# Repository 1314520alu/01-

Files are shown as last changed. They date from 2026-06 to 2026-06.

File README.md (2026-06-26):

# 01飞控 — X9 Core 多旋翼底板

为零一飞行 [X9 Core](https://docs.01aero.cn/docs/JfRLkT8E) 设计多旋翼载板（EasyEDA）。

## 文档

| 文件 | 说明 |
|---|---|
| [docs/X9-Core-多旋翼底板-接口设计说明.md](docs/X9-Core-多旋翼底板-接口设计说明.md) | 接口需求、电源架构、串口映射、PWM/CAN 分配 |
| [docs/DF17/](docs/DF17/) | DF17 引脚：Core（[80DS](docs/DF17/DF17-80DS-pinout.md)/[80DP](docs/DF17/DF17-80DP-pinout.md)）+ 载板（[carrier-80DS](docs/DF17/carrier-80DS-pinout.md)/[carrier-80DP](docs/DF17/carrier-80DP-pinout.md)） |
| [db/pinout.db](db/pinout.db) | SQLite 引脚库（`python tools/import_df17_pinout.py` 同步） |
| [docs/DF17/cad/](docs/DF17/cad/) | X9 Core 底面 DXF 机械图 |

## 下一步

1. 向零一飞行索取 **DF17 封装尺寸 DXF**（pinout 已录入 [docs/DF17/](docs/DF17/)）
2. 在 EasyEDA 按设计说明第 9 节分区绘制原理图
3. 载板原理图标网以 [carrier-80DS/80DP](docs/DF17/) 为准（载板 DS←Core DP，载板 DP←Core DS）

## 固件

- 机型：**ArduCopter**
- 固件：[零一 X9 ArduPilot 资源](https://pan.01aero.cn/s/mYhv零一飞行资源库/X9系列飞控/ArduPilot固件)

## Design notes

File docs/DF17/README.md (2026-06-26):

# DF17 连接器资料

X9 Core 底部有两颗 **80pin** 板对板 DF17 连接器，载板设计需同时对接。

## 参考图

| 图 | 说明 |
|----|---|
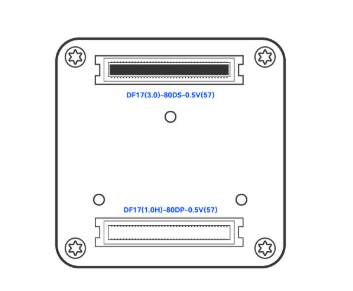
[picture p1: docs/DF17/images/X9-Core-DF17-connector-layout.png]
座子布局
|  | 飞控底部两颗 DF17 位置（上 **80DS**、下 **80DP**） |
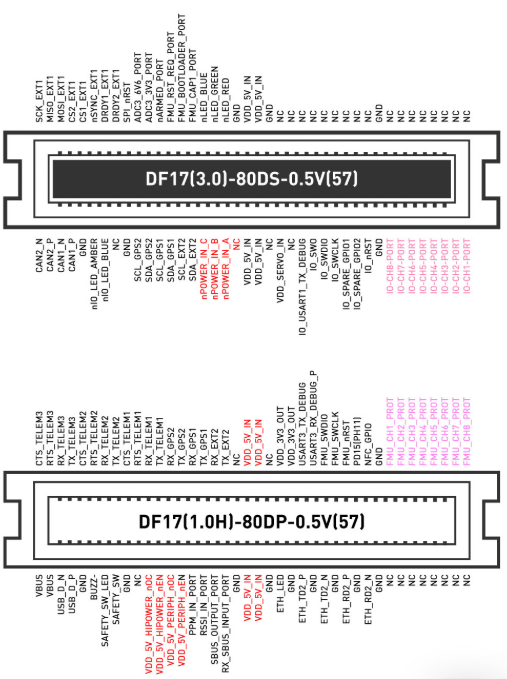
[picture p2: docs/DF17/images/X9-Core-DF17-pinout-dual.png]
双座子引脚图
|  | 80DS + 80DP 完整引脚图（官方） |

源文件：

- [images/X9-Core-DF17-connector-layout.png](images/X9-Core-DF17-connector-layout.png)
- [images/X9-Core-DF17-pinout-dual.png](images/X9-Core-DF17-pinout-dual.png)

## CAD（底面机械）

| 文件 | 说明 |
|---|---|
| [cad/X9-Core-bottom.dxf](cad/X9-Core-bottom.dxf) | Core 底面机械 DXF |
| [cad/carrier-pcb.dxf](cad/carrier-pcb.dxf) | **载板 PCB DXF**（Top View，导入 EasyEDA） |
| [cad/X9-Core-bottom-reference.png](cad/X9-Core-bottom-reference.png) | 官方底面机械图 |
| [cad/README.md](cad/README.md) | 图层、尺寸、生成说明 |

```bash
pip install ezdxf
python tools/generate_x9_bottom_cad.py
python tools/generate_carrier_pcb_dxf.py
```

## 原理图（Core 载板 · 仅双 DF17）

| 文件 | 说明 |
|---|---|
| [schematic/Core底板-原理图.md](schematic/Core底板-原理图.md) | 单页原理图规格：J1(80DP) + J2(80DS) |
| [schematic/core-carrier-schematic-spec.json](schematic/core-carrier-schematic-spec.json) | 机器可读引脚/布局规格 |

生成：`python tools/setup_core_carrier_schematic.py`

## JLCEDA MCP

Cursor ↔ 嘉立创 EDA 桥接：`ws://127.0.0.1:8760/bridge/ws`  
配置与故障修复见 [JLCEDA-MCP-配置与修复.md](JLCEDA-MCP-配置与修复.md)

| 座子型号 | 文档 | 视角 | 主要功能 |
|---|---|---|---|
| DF17(3.0)-80DS-0.5V(57) | [DF17-80DS-pinout.md](DF17-80DS-pinout.md) | **Core** | SPI、CAN、I2C、IO 侧 PWM/SWD |
| DF17(1.0H)-80DP-0.5V(57) | [DF17-80DP-pinout.md](DF17-80DP-pinout.md) | **Core** | UART、FMU PWM、以太网、USB、RC、电源控制 |
| DF17(3.0)-80DS-0.5V(57) | [carrier-80DS-pinout.md](carrier-80DS-pinout.md) | **载板 −Y** | 对接 Core 80DP，网络同 Core DP 表 |
| DF17(1.0H)-80DP-0.5V(57) | [carrier-80DP-pinout.md](carrier-80DP-pinout.md) | **载板 +Y** | 对接 Core 80DS，网络同 Core DS 表 |

## 原理图放置（LCSC 标准符号）

**原理图页面**与 Core 官方引脚图同序（上 80DS、下 80DP），便于对照；**PCB 贴装**仍为 +Y=80DP、−Y=80DS。

| 原理图 | 座子 | PCB | rotation | mirror | Pin1 位置 |
|---|---|-----|---|---|---|
| 上 J1 | 80DS | −Y | **90** | **true** | 右上 |
| 下 J2 | 80DP | +Y | **270** | **true** | 左下 |

各座子标网取自 **载板引脚表**（[carrier-80DS](carrier-80DS-pinout.md) / [carrier-80DP](carrier-80DP-pinout.md)：载板 DS←Core DP，载板 DP←Core DS）。

勿用 rotation=270 **无**镜像，或两座子相同 rotation——会导致与 Core 文档不对称。

## 数据库

结构化数据存放在 SQLite：`db/pinout.db`

| 文件 | 说明 |
|---|---|
| [db/schema.sql](../db/schema.sql) | 表结构（products / connectors / pins） |
| [tools/import_df17_pinout.py](../tools/import_df17_pinout.py) | 从 Markdown 导入/更新数据库 |

```bash
python tools/generate_carrier_pinout_md.py   # 从 Core md 生载板 md
python tools/import_df17_pinout.py
python tools/setup_core_carrier_schematic.py
```

常用查询示例：

```sql
-- 载板 80DP 全部引脚
SELECT pin_number, signal_name, category
FROM pins p JOIN connectors c ON p.connector_id = c.id
WHERE c.part_number = 'DF17(1.0H)-80DP-0.5V(57)' AND c.role = 'carrier'
ORDER BY pin_number;

-- Core 80DS 全部引脚
SELECT pin_number, signal_name, category
FROM pins p JOIN connectors c ON p.connector_id = c.id
WHERE c.part_number = 'DF17(3.0)-80DS-0.5V(57)' AND c.role = 'core'
ORDER BY pin_number;

-- 按信号名搜索（含载板）
SELECT c.role, c.part_number, p.pin_number, p.signal_name
FROM pins p JOIN connectors c ON p.connector_id = c.id
WHERE p.signal_name LIKE '%CAN%'
ORDER BY c.role, c.part_number, p.pin_number;
```

## 编号约定

**Core 底视**（两颗座子相同）：

- 上排奇数：**1, 3, 5, …, 79**（左 → 右）
- 下排偶数：**2, 4, 6, …, 80**（左 → 右）
- 四角：**Pin1 左上 · Pin2 左下 · Pin79 右上 · Pin80 右下**

**载板 PCB**（Top View，相对 Core 左右 180° 镜像）：

- **Pin1 右上 · Pin2 右下 · Pin79 左上 · Pin80 左下**
- 载板 **DP 配 Core DS**，载板 **DS 配 Core DP**

## 待补充

- [x] 底面机械 CAD（见 [cad/X9-Core-bottom.dxf](cad/X9-Core-bottom.dxf)；M2 孔位待官方复核）
- [x] 载板侧网络名（见 [carrier-80DS-pinout.md](carrier-80DS-pinout.md)、[carrier-80DP-pinout.md](carrier-80DP-pinout.md)）

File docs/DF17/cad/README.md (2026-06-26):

# X9 Core 底面 CAD

根据官方底面机械图生成的可编辑 CAD 文件，用于 EasyEDA / Altium / FreeCAD 等导入参考。

## 文件

| 文件 | 说明 |
|---|---|
| [X9-Core-bottom.dxf](X9-Core-bottom.dxf) | Core 底面机械参考（Bottom View） |
| [carrier-pcb.dxf](carrier-pcb.dxf) | **载板 PCB 用**（Top View，可直接导入 EasyEDA） |
| [X9-Core-bottom-reference.png](X9-Core-bottom-reference.png) | 官方底面机械图扫描/截图 |

## 生成

```bash
pip install ezdxf
python tools/generate_x9_bottom_cad.py      # Core 底面机械
python tools/generate_carrier_pcb_dxf.py    # 载板 PCB
```

## 图层

| 图层 | 内容 |
|---|---|
| `OUTLINE` | 外形 38.80×38.80（R3 圆角） |
| `MOUNT_HOLES` | 四角安装孔 φ2.10 通孔 |
| `MOUNT_CB` | 沉孔 φ3.60×0.65 |
| `CONNECTOR` | 两颗 DF17 壳体投影 4×24 mm |
| `DF17_PADS` | 80pin 0.5mm pitch 焊盘参考 |
| `CENTER_RIBS` | 中央加强筋示意 |
| `M2_HOLES` | 3×φ1.60 / M2-6H |
| `PIN1_MARK` | Pin1 位置标记 |
| `DIM` / `TEXT` | 尺寸与说明 |

## 关键尺寸（mm）

| 项目 | 值 |
|---|-----|
| 外形 | 38.80 × 38.80 |
| 安装孔距 | 32 × 32（中心 ±16） |
| 安装孔 | φ2.10 通孔，沉孔 φ3.60↓0.65 |
| 连接器中心 | X = ±16 |
| 连接器投影 | 4 × 24 |
| 中央筋位宽度 | 14 |
| M2 孔 | 3×φ1.60↓3 |

**坐标原点：** 几何中心 `(0, 0)`  
**视图：** 底面（Bottom View），沿 −Z 看向 Core 底面

---

## carrier-pcb.dxf（载板 PCB）

| 项目 | 说明 |
|---|-----|
| 视图 | **载板 Top View**（PCB 设计视角，已按 mating 配对 DS/DP） |
| 板框 | 80 × 80 mm（可导入后改大） |
| Core 占位 | 38.80 虚线框 |
| 安装孔 | 32 × 32，φ2.50（M2 螺丝） |
| 上侧 (+Y) | **80DP**（对接 Core 80DS） |
| 下侧 (−Y) | **80DS**（对接 Core 80DP） |
| Pin1 | Core 底视每颗连接器 **左上**（Pin2 左下）；载板 **右上**（镜像） |

### EasyEDA 导入

1. PCB 编辑器 → **文件 → 导入 → DXF**
2. 图层映射：`BOARD_OUTLINE` → 板框；`DRILL`/`HOLE` → 钻孔；`PAD`/`FOOTPRINT` → 参考
3. **焊盘请换用 Hirose 官方 footprint**，DXF 中 PAD 仅为对齐参考
4. 以 **PIN1** 标记与官方封装 Pin1 重合为验收标准

## 注意事项（Core 底面 DXF）

1. **M2 孔 Y 坐标**（±6 mm）为按底图比例估算，正式开模/开板前请与零一官方 DXF 复核。
2. **DF17 焊盘**按 Hirose 0.5 mm pitch、80pin 双列生成，仅为参考；载板应使用官方 DS/DP footprint。
3. 布局示意图（[connector-layout](../images/X9-Core-DF17-connector-layout.png)）为 **上 80DS / 下 80DP** 示意；本机械图为 **左 / 右** 两颗连接器投影，设计时以本 DXF 尺寸为准并镜像到载板。

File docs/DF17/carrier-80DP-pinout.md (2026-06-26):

# 载板 DF17(1.0H)-80DP-0.5V(57) 引脚定义

| 项目 | 说明 |
|---|---|
| 角色 | **载板** |
| 座子型号 | DF17(1.0H)-80DP-0.5V(57) |
| 引脚总数 | 80 |
| 载板位置 | PCB **+Y** |
| 对接 Core | **80DS** |
| 网络来源 | 同 Pin 号取自 [Core 80DS](DF17-80DS-pinout.md) |
| 编号约定 | 上排奇数 Pin1,3,…,79（左→右）；下排偶数 Pin2,4,…,80（左→右） |
| 载板 Top View | Pin1 **右上** · Pin2 **右下** · Pin79 **左上** · Pin80 **左下**（相对 Core 底视左右 180° 镜像） |

> 载板原理图/PCB 标网用本表。Core 侧定义见 [80DS](DF17-80DS-pinout.md)。

---

## 完整引脚表（Pin 1–80）

| Pin | 信号名 | 类别 | Pin | 信号名 | 类别 |
|-----|---|---|-----|---|---|
| 1 | SCK_EXT1 | SPI EXT1 | 2 | CAN2_N | CAN |
| 3 | MISO_EXT1 | SPI EXT1 | 4 | CAN2_P | CAN |
| 5 | MOSI_EXT1 | SPI EXT1 | 6 | CAN1_N | CAN |
| 7 | CS2_EXT1 | SPI EXT1 | 8 | CAN1_P | CAN |
| 9 | CS1_EXT1 | SPI EXT1 | 10 | GND | 地 |
| 11 | nSYNC_EXT1 | SPI EXT1 | 12 | nIO_LED_AMBER | LED |
| 13 | DRDY1_EXT1 | SPI EXT1 | 14 | nIO_LED_BLUE | LED |
| 15 | DRDY2_EXT1 | SPI EXT1 | 16 | NC | — |
| 17 | SPI_nRST | SPI EXT1 | 18 | GND | 地 |
| 19 | ADC3_6V6_PORT | ADC | 20 | SCL_GPS2 | I2C GPS2 |
| 21 | ADC3_3V3_PORT | ADC | 22 | SDA_GPS2 | I2C GPS2 |
| 23 | nARMED_PORT | FMU | 24 | SCL_GPS1 | I2C GPS1 |
| 25 | FMU_RST_REQ_PORT | FMU | 26 | SDA_GPS1 | I2C GPS1 |
| 27 | FMU_BOOTLOADER_PORT | FMU | 28 | SCL_EXT2 | I2C EXT2 |
| 29 | FMU_CAP1_PORT | FMU | 30 | SDA_EXT2 | I2C EXT2 |
| 31 | nLED_BLUE | LED | 32 | nPOWER_IN_C | 电源检测 |
| 33 | nLED_GREEN | LED | 34 | nPOWER_IN_B | 电源检测 |
| 35 | nLED_RED | LED | 36 | nPOWER_IN_A | 电源检测 |
| 37 | GND | 地 | 38 | NC | — |
| 39 | VDD_5V_IN | 电源 | 40 | VDD_5V_IN | 电源 |
| 41 | VDD_5V_IN | 电源 | 42 | VDD_5V_IN | 电源 |
| 43 | GND | 地 | 44 | NC | — |
| 45 | NC | — | 46 | VDD_SERVO_IN | 电源 |
| 47 | NC | — | 48 | NC | — |
| 49 | NC | — | 50 | IO_USART1_TX_DEBUG | 调试串口 |
| 51 | NC | — | 52 | IO_SWO | SWD |
| 53 | NC | — | 54 | IO_SWDIO | SWD |
| 55 | NC | — | 56 | IO_SWCLK | SWD |
| 57 | NC | — | 58 | IO_SPARE_GPIO1 | GPIO |
| 59 | NC | — | 60 | IO_SPARE_GPIO2 | GPIO |
| 61 | NC | — | 62 | IO_nRST | IO |
| 63 | NC | — | 64 | GND | 地 |
| 65 | GND | 地 | 66 | IO-CH8-PORT | PWM/IO |
| 67 | NC | — | 68 | IO-CH7-PORT | PWM/IO |
| 69 | NC | — | 70 | IO-CH6-PORT | PWM/IO |
| 71 | NC | — | 72 | IO-CH5-PORT | PWM/IO |
| 73 | NC | — | 74 | IO-CH4-PORT | PWM/IO |
| 75 | NC | — | 76 | IO-CH3-PORT | PWM/IO |
| 77 | NC | — | 78 | IO-CH2-PORT | PWM/IO |
| 79 | NC | — | 80 | IO-CH1-PORT | PWM/IO |

---

## 按行排列（便于对照丝印）

### 上排奇数 Pin 1,3,…,79（左 → 右）

| 1 | 3 | 5 | 7 | 9 | 11 | 13 | 15 | 17 | 19 |
|---|---|---|---|---|---|---|---|---|---|
| SCK_EXT1 | MISO_EXT1 | MOSI_EXT1 | CS2_EXT1 | CS1_EXT1 | nSYNC_EXT1 | DRDY1_EXT1 | DRDY2_EXT1 | SPI_nRST | ADC3_6V6_PORT |

| 21 | 23 | 25 | 27 | 29 | 31 | 33 | 35 | 37 | 39 |
|---|---|---|---|---|---|---|---|---|---|
| ADC3_3V3_PORT | nARMED_PORT | FMU_RST_REQ_PORT | FMU_BOOTLOADER_PORT | FMU_CAP1_PORT | nLED_BLUE | nLED_GREEN | nLED_RED | GND | VDD_5V_IN |

| 41 | 43 | 45 | 47 | 49 | 51 | 53 | 55 | 57 | 59 |
|---|---|---|---|---|---|---|---|---|---|
| VDD_5V_IN | GND | NC | NC | NC | NC | NC | NC | NC | NC |

| 61 | 63 | 65 | 67 | 69 | 71 | 73 | 75 | 77 | 79 |
|---|---|---|---|---|---|---|---|---|---|
| NC | NC | GND | NC | NC | NC | NC | NC | NC | NC |

### 下排偶数 Pin 80,78,…,2（左 = 80，右 = 2）

| 80 | 78 | 76 | 74 | 72 | 70 | 68 | 66 | 64 | 62 |
|---|---|---|---|---|---|---|---|---|---|
| IO-CH1-PORT | IO-CH2-PORT | IO-CH3-PORT | IO-CH4-PORT | IO-CH5-PORT | IO-CH6-PORT | IO-CH7-PORT | IO-CH8-PORT | GND | IO_nRST |

| 60 | 58 | 56 | 54 | 52 | 50 | 48 | 46 | 44 | 42 |
|---|---|---|---|---|---|---|---|---|---|
| IO_SPARE_GPIO2 | IO_SPARE_GPIO1 | IO_SWCLK | IO_SWDIO | IO_SWO | IO_USART1_TX_DEBUG | NC | VDD_SERVO_IN | NC | VDD_5V_IN |

| 40 | 38 | 36 | 34 | 32 | 30 | 28 | 26 | 24 | 22 |
|---|---|---|---|---|---|---|---|---|---|
| VDD_5V_IN | NC | nPOWER_IN_A | nPOWER_IN_B | nPOWER_IN_C | SDA_EXT2 | SCL_EXT2 | SDA_GPS1 | SCL_GPS1 | SDA_GPS2 |

| 20 | 18 | 16 | 14 | 12 | 10 | 8 | 6 | 4 | 2 |
|---|---|---|---|---|---|---|---|---|---|
| SCL_GPS2 | GND | NC | nIO_LED_BLUE | nIO_LED_AMBER | GND | CAN1_P | CAN1_N | CAN2_P | CAN2_N |

---

## 修订记录

| 日期 | 说明 |
|---|---|
| 2026-06-25 | 由 Core 引脚表交叉映射生成（载板 DS←Core DP，载板 DP←Core DS） |

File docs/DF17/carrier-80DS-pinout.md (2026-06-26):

# 载板 DF17(3.0)-80DS-0.5V(57) 引脚定义

| 项目 | 说明 |
|---|---|
| 角色 | **载板** |
| 座子型号 | DF17(3.0)-80DS-0.5V(57) |
| 引脚总数 | 80 |
| 载板位置 | PCB **−Y** |
| 对接 Core | **80DP** |
| 网络来源 | 同 Pin 号取自 [Core 80DP](DF17-80DP-pinout.md) |
| 编号约定 | 上排奇数 Pin1,3,…,79（左→右）；下排偶数 Pin2,4,…,80（左→右） |
| 载板 Top View | Pin1 **右上** · Pin2 **右下** · Pin79 **左上** · Pin80 **左下**（相对 Core 底视左右 180° 镜像） |

> 载板原理图/PCB 标网用本表。Core 侧定义见 [80DP](DF17-80DP-pinout.md)。

---

## 完整引脚表（Pin 1–80）

| Pin | 信号名 | 类别 | Pin | 信号名 | 类别 |
|-----|---|---|-----|---|---|
| 1 | CTS_TELEM3 | UART TELEM3 | 2 | VBUS | USB |
| 3 | RTS_TELEM3 | UART TELEM3 | 4 | VBUS | USB |
| 5 | RX_TELEM3 | UART TELEM3 | 6 | USB_D_N | USB |
| 7 | TX_TELEM3 | UART TELEM3 | 8 | USB_D_P | USB |
| 9 | CTS_TELEM2 | UART TELEM2 | 10 | GND | 地 |
| 11 | RTS_TELEM2 | UART TELEM2 | 12 | BUZZ- | 蜂鸣器 |
| 13 | RX_TELEM2 | UART TELEM2 | 14 | SAFETY_SW_LED | 安全开关 |
| 15 | TX_TELEM2 | UART TELEM2 | 16 | SAFETY_SW | 安全开关 |
| 17 | CTS_TELEM1 | UART TELEM1 | 18 | GND | 地 |
| 19 | RTS_TELEM1 | UART TELEM1 | 20 | NC | — |
| 21 | RX_TELEM1 | UART TELEM1 | 22 | VDD_5V_HIPOWER_nOC | 电源控制 |
| 23 | TX_TELEM1 | UART TELEM1 | 24 | VDD_5V_HIPOWER_nEN | 电源控制 |
| 25 | RX_GPS2 | UART GPS2 | 26 | VDD_5V_PERIPH_nOC | 电源控制 |
| 27 | TX_GPS2 | UART GPS2 | 28 | VDD_5V_PERIPH_nEN | 电源控制 |
| 29 | RX_GPS1 | UART GPS1 | 30 | PPM_IN_PORT | RC |
| 31 | TX_GPS1 | UART GPS1 | 32 | RSSI_IN_PORT | RC |
| 33 | RX_EXT2 | UART EXT2 | 34 | SBUS_OUTPUT_PORT | RC |
| 35 | TX_EXT2 | UART EXT2 | 36 | RX_SBUS_INPUT_PORT | RC |
| 37 | NC | — | 38 | GND | 地 |
| 39 | VDD_5V_IN | 电源 | 40 | VDD_5V_IN | 电源 |
| 41 | VDD_5V_IN | 电源 | 42 | VDD_5V_IN | 电源 |
| 43 | NC | — | 44 | GND | 地 |
| 45 | VDD_3V3_OUT | 电源 | 46 | ETH_LED | 以太网 |
| 47 | VDD_3V3_OUT | 电源 | 48 | GND | 地 |
| 49 | USART3_TX_DEBUG | 调试串口 | 50 | ETH_TD2_P | 以太网 |
| 51 | USART3_RX_DEBUG_P | 调试串口 | 52 | GND | 地 |
| 53 | FMU_SWDIO | SWD | 54 | ETH_TD2_N | 以太网 |
| 55 | FMU_SWCLK | SWD | 56 | GND | 地 |
| 57 | FMU_nRST | FMU | 58 | ETH_RD2_P | 以太网 |
| 59 | PD15(PH11) | GPIO | 60 | GND | 地 |
| 61 | NFC_GPIO | GPIO | 62 | ETH_RD2_N | 以太网 |
| 63 | GND | 地 | 64 | GND | 地 |
| 65 | FMU_CH1_PROT | PWM | 66 | NC | — |
| 67 | FMU_CH2_PROT | PWM | 68 | NC | — |
| 69 | FMU_CH3_PROT | PWM | 70 | NC | — |
| 71 | FMU_CH4_PROT | PWM | 72 | NC | — |
| 73 | FMU_CH5_PROT | PWM | 74 | NC | — |
| 75 | FMU_CH6_PROT | PWM | 76 | NC | — |
| 77 | FMU_CH7_PROT | PWM | 78 | NC | — |
| 79 | FMU_CH8_PROT | PWM | 80 | NC | — |

---

## 按行排列（便于对照丝印）

### 上排奇数 Pin 1,3,…,79（左 → 右）

| 1 | 3 | 5 | 7 | 9 | 11 | 13 | 15 | 17 | 19 |
|---|---|---|---|---|---|---|---|---|---|
| CTS_TELEM3 | RTS_TELEM3 | RX_TELEM3 | TX_TELEM3 | CTS_TELEM2 | RTS_TELEM2 | RX_TELEM2 | TX_TELEM2 | CTS_TELEM1 | RTS_TELEM1 |

| 21 | 23 | 25 | 27 | 29 | 31 | 33 | 35 | 37 | 39 |
|---|---|---|---|---|---|---|---|---|---|
| RX_TELEM1 | TX_TELEM1 | RX_GPS2 | TX_GPS2 | RX_GPS1 | TX_GPS1 | RX_EXT2 | TX_EXT2 | NC | VDD_5V_IN |

| 41 | 43 | 45 | 47 | 49 | 51 | 53 | 55 | 57 | 59 |
|---|---|---|---|---|---|---|---|---|---|
| VDD_5V_IN | NC | VDD_3V3_OUT | VDD_3V3_OUT | USART3_TX_DEBUG | USART3_RX_DEBUG_P | FMU_SWDIO | FMU_SWCLK | FMU_nRST | PD15(PH11) |

| 61 | 63 | 65 | 67 | 69 | 71 | 73 | 75 | 77 | 79 |
|---|---|---|---|---|---|---|---|---|---|
| NFC_GPIO | GND | FMU_CH1_PROT | FMU_CH2_PROT | FMU_CH3_PROT | FMU_CH4_PROT | FMU_CH5_PROT | FMU_CH6_PROT | FMU_CH7_PROT | FMU_CH8_PROT |

### 下排偶数 Pin 80,78,…,2（左 = 80，右 = 2）

| 80 | 78 | 76 | 74 | 72 | 70 | 68 | 66 | 64 | 62 |
|---|---|---|---|---|---|---|---|---|---|
| NC | NC | NC | NC | NC | NC | NC | NC | GND | ETH_RD2_N |

| 60 | 58 | 56 | 54 | 52 | 50 | 48 | 46 | 44 | 42 |
|---|---|---|---|---|---|---|---|---|---|
| GND | ETH_RD2_P | GND | ETH_TD2_N | GND | ETH_TD2_P | GND | ETH_LED | GND | VDD_5V_IN |

| 40 | 38 | 36 | 34 | 32 | 30 | 28 | 26 | 24 | 22 |
|---|---|---|---|---|---|---|---|---|---|
| VDD_5V_IN | GND | RX_SBUS_INPUT_PORT | SBUS_OUTPUT_PORT | RSSI_IN_PORT | PPM_IN_PORT | VDD_5V_PERIPH_nEN | VDD_5V_PERIPH_nOC | VDD_5V_HIPOWER_nEN | VDD_5V_HIPOWER_nOC |

| 20 | 18 | 16 | 14 | 12 | 10 | 8 | 6 | 4 | 2 |
|---|---|---|---|---|---|---|---|---|---|
| NC | GND | SAFETY_SW | SAFETY_SW_LED | BUZZ- | GND | USB_D_P | USB_D_N | VBUS | VBUS |

---

## 修订记录

| 日期 | 说明 |
|---|---|
| 2026-06-25 | 由 Core 引脚表交叉映射生成（载板 DS←Core DP，载板 DP←Core DS） |

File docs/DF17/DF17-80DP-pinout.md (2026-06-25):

# DF17(1.0H)-80DP-0.5V(57) 引脚定义

| 项目 | 说明 |
|---|---|
| 座子型号 | DF17(1.0H)-80DP-0.5V(57) |
| 引脚总数 | 80 |
| 编号约定 | **Core 底视**：左上=Pin1，左下=Pin80 · **载板原理图（rot180）**：右上=Pin1，左下=Pin80（右下=Pin79，见说明） |
| 上行 | Pin 1 → 40，自左向右 |
| 下行 | Pin 80 → 41，自左向右 |

> 飞控底部视图；载板侧连接器需镜像反向。与 [80DS 座子](DF17-80DS-pinout.md) 配对使用。

---

## 完整引脚表（Pin 1–80）

| Pin | 信号名 | 类别 | Pin | 信号名 | 类别 |
|-----|---|---|-----|---|---|
| 1 | CTS_TELEM3 | UART TELEM3 | 41 | NC | — |
| 2 | RTS_TELEM3 | UART TELEM3 | 42 | NC | — |
| 3 | RX_TELEM3 | UART TELEM3 | 43 | NC | — |
| 4 | TX_TELEM3 | UART TELEM3 | 44 | NC | — |
| 5 | CTS_TELEM2 | UART TELEM2 | 45 | NC | — |
| 6 | RTS_TELEM2 | UART TELEM2 | 46 | NC | — |
| 7 | RX_TELEM2 | UART TELEM2 | 47 | NC | — |
| 8 | TX_TELEM2 | UART TELEM2 | 48 | NC | — |
| 9 | CTS_TELEM1 | UART TELEM1 | 49 | GND | 地 |
| 10 | RTS_TELEM1 | UART TELEM1 | 50 | ETH_RD2_N | 以太网 |
| 11 | RX_TELEM1 | UART TELEM1 | 51 | GND | 地 |
| 12 | TX_TELEM1 | UART TELEM1 | 52 | ETH_RD2_P | 以太网 |
| 13 | RX_GPS2 | UART GPS2 | 53 | GND | 地 |
| 14 | TX_GPS2 | UART GPS2 | 54 | ETH_TD2_N | 以太网 |
| 15 | RX_GPS1 | UART GPS1 | 55 | GND | 地 |
| 16 | TX_GPS1 | UART GPS1 | 56 | ETH_TD2_P | 以太网 |
| 17 | RX_EXT2 | UART EXT2 | 57 | GND | 地 |
| 18 | TX_EXT2 | UART EXT2 | 58 | ETH_LED | 以太网 |
| 19 | NC | — | 59 | GND | 地 |
| 20 | VDD_5V_IN | 电源 | 60 | VDD_5V_IN | 电源 |
| 21 | VDD_5V_IN | 电源 | 61 | VDD_5V_IN | 电源 |
| 22 | NC | — | 62 | GND | 地 |
| 23 | VDD_3V3_OUT | 电源 | 63 | RX_SBUS_INPUT_PORT | RC |
| 24 | VDD_3V3_OUT | 电源 | 64 | SBUS_OUTPUT_PORT | RC |
| 25 | USART3_TX_DEBUG | 调试串口 | 65 | RSSI_IN_PORT | RC |
| 26 | USART3_RX_DEBUG_P | 调试串口 | 66 | PPM_IN_PORT | RC |
| 27 | FMU_SWDIO | SWD | 67 | VDD_5V_PERIPH_nEN | 电源控制 |
| 28 | FMU_SWCLK | SWD | 68 | VDD_5V_PERIPH_nOC | 电源控制 |
| 29 | FMU_nRST | FMU | 69 | VDD_5V_HIPOWER_nEN | 电源控制 |
| 30 | PD15(PH11) | GPIO | 70 | VDD_5V_HIPOWER_nOC | 电源控制 |
| 31 | NFC_GPIO | GPIO | 71 | NC | — |
| 32 | GND | 地 | 72 | GND | 地 |
| 33 | FMU_CH1_PROT | PWM | 73 | SAFETY_SW | 安全开关 |
| 34 | FMU_CH2_PROT | PWM | 74 | SAFETY_SW_LED | 安全开关 |
| 35 | FMU_CH3_PROT | PWM | 75 | BUZZ- | 蜂鸣器 |
| 36 | FMU_CH4_PROT | PWM | 76 | GND | 地 |
| 37 | FMU_CH5_PROT | PWM | 77 | USB_D_P | USB |
| 38 | FMU_CH6_PROT | PWM | 78 | USB_D_N | USB |
| 39 | FMU_CH7_PROT | PWM | 79 | VBUS | USB |
| 40 | FMU_CH8_PROT | PWM | 80 | VBUS | USB |

---

## 按行排列（便于对照丝印）

### 上行 Pin 1–40（左 → 右）

| 1 | 2 | 3 | 4 | 5 | 6 | 7 | 8 | 9 | 10 |
|---|---|---|---|---|---|---|---|---|---|
| CTS_TELEM3 | RTS_TELEM3 | RX_TELEM3 | TX_TELEM3 | CTS_TELEM2 | RTS_TELEM2 | RX_TELEM2 | TX_TELEM2 | CTS_TELEM1 | RTS_TELEM1 |

| 11 | 12 | 13 | 14 | 15 | 16 | 17 | 18 | 19 | 20 |
|----|----|----|----|----|----|----|----|----|-----|
| RX_TELEM1 | TX_TELEM1 | RX_GPS2 | TX_GPS2 | RX_GPS1 | TX_GPS1 | RX_EXT2 | TX_EXT2 | NC | VDD_5V_IN |

| 21 | 22 | 23 | 24 | 25 | 26 | 27 | 28 | 29 | 30 |
|----|----|----|----|----|----|----|----|----|-----|
| VDD_5V_IN | NC | VDD_3V3_OUT | VDD_3V3_OUT | USART3_TX_DEBUG | USART3_RX_DEBUG_P | FMU_SWDIO | FMU_SWCLK | FMU_nRST | PD15(PH11) |

| 31 | 32 | 33 | 34 | 35 | 36 | 37 | 38 | 39 | 40 |
|----|----|----|----|----|----|----|----|----|-----|
| NFC_GPIO | GND | FMU_CH1_PROT | FMU_CH2_PROT | FMU_CH3_PROT | FMU_CH4_PROT | FMU_CH5_PROT | FMU_CH6_PROT | FMU_CH7_PROT | FMU_CH8_PROT |

### 下行 Pin 80–41（左 = 80，右 = 41）

| 80 | 79 | 78 | 77 | 76 | 75 | 74 | 73 | 72 | 71 |
|----|----|----|----|----|----|----|----|----|-----|
| VBUS | VBUS | USB_D_N | USB_D_P | GND | BUZZ- | SAFETY_SW_LED | SAFETY_SW | GND | NC |

| 70 | 69 | 68 | 67 | 66 | 65 | 64 | 63 | 62 | 61 |
|----|----|----|----|----|----|----|----|----|-----|
| VDD_5V_HIPOWER_nOC | VDD_5V_HIPOWER_nEN | VDD_5V_PERIPH_nOC | VDD_5V_PERIPH_nEN | PPM_IN_PORT | RSSI_IN_PORT | SBUS_OUTPUT_PORT | RX_SBUS_INPUT_PORT | GND | VDD_5V_IN |

| 60 | 59 | 58 | 57 | 56 | 55 | 54 | 53 | 52 | 51 |
|----|----|----|----|----|----|----|----|----|-----|
| VDD_5V_IN | GND | ETH_LED | GND | ETH_TD2_P | GND | ETH_TD2_N | GND | ETH_RD2_P | GND |

| 50 | 49 | 48 | 47 | 46 | 45 | 44 | 43 | 42 | 41 |
|----|----|----|----|----|----|----|----|----|-----|
| ETH_RD2_N | GND | NC | NC | NC | NC | NC | NC | NC | NC |

---

## 功能分组

### 电源

| Pin | 信号名 | 说明 |
|-----|---|---|
| 20, 21, 60, 61 | VDD_5V_IN | 5 V 输入 |
| 23, 24 | VDD_3V3_OUT | 3.3 V 输出 |
| 67 | VDD_5V_PERIPH_nEN | 外设 5 V 使能 |
| 68 | VDD_5V_PERIPH_nOC | 外设 5 V 过流 |
| 69 | VDD_5V_HIPOWER_nEN | 大功率 5 V 使能 |
| 70 | VDD_5V_HIPOWER_nOC | 大功率 5 V 过流 |
| 79, 80 | VBUS | USB 5 V |

### 地（GND）

Pin：**32, 49, 51, 53, 55, 57, 59, 62, 72, 76**

### UART / 串口

| 接口 | CTS | RTS | RX | TX |
|---|-----|-----|----|----|
| TELEM3 | 1 | 2 | 3 | 4 |
| TELEM2 | 5 | 6 | 7 | 8 |
| TELEM1 | 9 | 10 | 11 | 12 |
| GPS2 | — | — | 13 | 14 |
| GPS1 | — | — | 15 | 16 |
| EXT2 | — | — | 17 | 18 |
| DEBUG | — | — | 26 | 25 |

### FMU PWM 输出（带保护）

| Pin | 信号名 |
|-----|---|
| 33 | FMU_CH1_PROT |
| 34 | FMU_CH2_PROT |
| 35 | FMU_CH3_PROT |
| 36 | FMU_CH4_PROT |
| 37 | FMU_CH5_PROT |
| 38 | FMU_CH6_PROT |
| 39 | FMU_CH7_PROT |
| 40 | FMU_CH8_PROT |

### 以太网（RGMII / PHY 相关）

| Pin | 信号名 |
|-----|---|
| 50 | ETH_RD2_N |
| 52 | ETH_RD2_P |
| 54 | ETH_TD2_N |
| 56 | ETH_TD2_P |
| 58 | ETH_LED |

### USB

| Pin | 信号名 |
|-----|---|
| 77 | USB_D_P |
| 78 | USB_D_N |
| 79, 80 | VBUS |

### RC 输入 / 输出

| Pin | 信号名 |
|-----|---|
| 63 | RX_SBUS_INPUT_PORT |
| 64 | SBUS_OUTPUT_PORT |
| 65 | RSSI_IN_PORT |
| 66 | PPM_IN_PORT |

### SWD 调试（FMU 侧）

| Pin | 信号名 |
|-----|---|
| 27 | FMU_SWDIO |
| 28 | FMU_SWCLK |
| 29 | FMU_nRST |

### 安全开关 / 蜂鸣器

| Pin | 信号名 |
|-----|---|
| 73 | SAFETY_SW |
| 74 | SAFETY_SW_LED |
| 75 | BUZZ- |

### GPIO

| Pin | 信号名 |
|-----|---|
| 30 | PD15(PH11) |
| 31 | NFC_GPIO |

### 未连接（NC）

Pin：**19, 22, 41–48, 71**

---

## 修订记录

| 日期 | 说明 |
|---|---|
| 2026-06-25 | 从零一 X9 Core DF17 引脚图提取，约定左上=1、左下=80 |

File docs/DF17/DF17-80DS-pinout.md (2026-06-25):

# DF17(3.0)-80DS-0.5V(57) 引脚定义

| 项目 | 说明 |
|---|---|
| 座子型号 | DF17(3.0)-80DS-0.5V(57) |
| 引脚总数 | 80 |
| 编号约定 | **Core 底视**：左上=Pin1，左下=Pin80 · **载板原理图（rot180）**：右上=Pin1，左下=Pin80（右下=Pin79，见说明） |
| 上行 | Pin 1 → 40，自左向右 |
| 下行 | Pin 80 → 41，自左向右 |

> 飞控底部视图；载板侧连接器需镜像反向（见 [X9-Core 多旋翼底板接口设计说明](../X9-Core-多旋翼底板-接口设计说明.md)）。与 [80DP 座子](DF17-80DP-pinout.md) 配对使用。

---

## 完整引脚表（Pin 1–80）

| Pin | 信号名 | 类别 | Pin | 信号名 | 类别 |
|-----|---|---|-----|---|---|
| 1 | SCK_EXT1 | SPI EXT1 | 41 | IO-CH1-PORT | PWM/IO |
| 2 | MISO_EXT1 | SPI EXT1 | 42 | IO-CH2-PORT | PWM/IO |
| 3 | MOSI_EXT1 | SPI EXT1 | 43 | IO-CH3-PORT | PWM/IO |
| 4 | CS2_EXT1 | SPI EXT1 | 44 | IO-CH4-PORT | PWM/IO |
| 5 | CS1_EXT1 | SPI EXT1 | 45 | IO-CH5-PORT | PWM/IO |
| 6 | nSYNC_EXT1 | SPI EXT1 | 46 | IO-CH6-PORT | PWM/IO |
| 7 | DRDY1_EXT1 | SPI EXT1 | 47 | IO-CH7-PORT | PWM/IO |
| 8 | DRDY2_EXT1 | SPI EXT1 | 48 | IO-CH8-PORT | PWM/IO |
| 9 | SPI_nRST | SPI EXT1 | 49 | GND | 地 |
| 10 | ADC3_6V6_PORT | ADC | 50 | IO_nRST | IO |
| 11 | ADC3_3V3_PORT | ADC | 51 | IO_SPARE_GPIO2 | GPIO |
| 12 | nARMED_PORT | FMU | 52 | IO_SPARE_GPIO1 | GPIO |
| 13 | FMU_RST_REQ_PORT | FMU | 53 | IO_SWCLK | SWD |
| 14 | FMU_BOOTLOADER_PORT | FMU | 54 | IO_SWDIO | SWD |
| 15 | FMU_CAP1_PORT | FMU | 55 | IO_SWO | SWD |
| 16 | nLED_BLUE | LED | 56 | IO_USART1_TX_DEBUG | 调试串口 |
| 17 | nLED_GREEN | LED | 57 | NC | — |
| 18 | nLED_RED | LED | 58 | VDD_SERVO_IN | 电源 |
| 19 | GND | 地 | 59 | NC | — |
| 20 | VDD_5V_IN | 电源 | 60 | VDD_5V_IN | 电源 |
| 21 | VDD_5V_IN | 电源 | 61 | VDD_5V_IN | 电源 |
| 22 | GND | 地 | 62 | NC | — |
| 23 | NC | — | 63 | nPOWER_IN_A | 电源检测 |
| 24 | NC | — | 64 | nPOWER_IN_B | 电源检测 |
| 25 | NC | — | 65 | nPOWER_IN_C | 电源检测 |
| 26 | NC | — | 66 | SDA_EXT2 | I2C EXT2 |
| 27 | NC | — | 67 | SCL_EXT2 | I2C EXT2 |
| 28 | NC | — | 68 | SDA_GPS1 | I2C GPS1 |
| 29 | NC | — | 69 | SCL_GPS1 | I2C GPS1 |
| 30 | NC | — | 70 | SDA_GPS2 | I2C GPS2 |
| 31 | NC | — | 71 | SCL_GPS2 | I2C GPS2 |
| 32 | NC | — | 72 | GND | 地 |
| 33 | GND | 地 | 73 | NC | — |
| 34 | NC | — | 74 | nIO_LED_BLUE | LED |
| 35 | NC | — | 75 | nIO_LED_AMBER | LED |
| 36 | NC | — | 76 | GND | 地 |
| 37 | NC | — | 77 | CAN1_P | CAN |
| 38 | NC | — | 78 | CAN1_N | CAN |
| 39 | NC | — | 79 | CAN2_P | CAN |
| 40 | NC | — | 80 | CAN2_N | CAN |

---

## 按行排列（便于对照丝印）

### 上行 Pin 1–40（左 → 右）

| 1 | 2 | 3 | 4 | 5 | 6 | 7 | 8 | 9 | 10 |
|---|---|---|---|---|---|---|---|---|---|
| SCK_EXT1 | MISO_EXT1 | MOSI_EXT1 | CS2_EXT1 | CS1_EXT1 | nSYNC_EXT1 | DRDY1_EXT1 | DRDY2_EXT1 | SPI_nRST | ADC3_6V6_PORT |

| 11 | 12 | 13 | 14 | 15 | 16 | 17 | 18 | 19 | 20 |
|----|----|----|----|----|----|----|----|----|-----|
| ADC3_3V3_PORT | nARMED_PORT | FMU_RST_REQ_PORT | FMU_BOOTLOADER_PORT | FMU_CAP1_PORT | nLED_BLUE | nLED_GREEN | nLED_RED | GND | VDD_5V_IN |

| 21 | 22 | 23 | 24 | 25 | 26 | 27 | 28 | 29 | 30 |
|----|----|----|----|----|----|----|----|----|-----|
| VDD_5V_IN | GND | NC | NC | NC | NC | NC | NC | NC | NC |

| 31 | 32 | 33 | 34 | 35 | 36 | 37 | 38 | 39 | 40 |
|----|----|----|----|----|----|----|----|----|-----|
| NC | NC | GND | NC | NC | NC | NC | NC | NC | NC |

### 下行 Pin 80–41（左 = 80，右 = 41）

| 80 | 79 | 78 | 77 | 76 | 75 | 74 | 73 | 72 | 71 |
|----|----|----|----|----|----|----|----|----|-----|
| CAN2_N | CAN2_P | CAN1_N | CAN1_P | GND | nIO_LED_AMBER | nIO_LED_BLUE | NC | GND | SCL_GPS2 |

| 70 | 69 | 68 | 67 | 66 | 65 | 64 | 63 | 62 | 61 |
|----|----|----|----|----|----|----|----|----|-----|
| SDA_GPS2 | SCL_GPS1 | SDA_GPS1 | SCL_EXT2 | SDA_EXT2 | nPOWER_IN_C | nPOWER_IN_B | nPOWER_IN_A | NC | VDD_5V_IN |

| 60 | 59 | 58 | 57 | 56 | 55 | 54 | 53 | 52 | 51 |
|----|----|----|----|----|----|----|----|----|-----|
| VDD_5V_IN | NC | VDD_SERVO_IN | NC | IO_USART1_TX_DEBUG | IO_SWO | IO_SWDIO | IO_SWCLK | IO_SPARE_GPIO1 | IO_SPARE_GPIO2 |

| 50 | 49 | 48 | 47 | 46 | 45 | 44 | 43 | 42 | 41 |
|----|----|----|----|----|----|----|----|----|-----|
| IO_nRST | GND | IO-CH8-PORT | IO-CH7-PORT | IO-CH6-PORT | IO-CH5-PORT | IO-CH4-PORT | IO-CH3-PORT | IO-CH2-PORT | IO-CH1-PORT |

---

## 功能分组

### 电源

| Pin | 信号名 | 说明 |
|-----|---|---|
| 20, 21, 60, 61 | VDD_5V_IN | 5 V 输入 |
| 58 | VDD_SERVO_IN | 舵机/外设 5 V 输入 |
| 63 | nPOWER_IN_A | 电源输入检测 A |
| 64 | nPOWER_IN_B | 电源输入检测 B |
| 65 | nPOWER_IN_C | 电源输入检测 C |

### 地（GND）

Pin：**19, 22, 33, 49, 72, 76**

### PWM / IO 通道

| Pin | 信号名 |
|-----|---|
| 41 | IO-CH1-PORT |
| 42 | IO-CH2-PORT |
| 43 | IO-CH3-PORT |
| 44 | IO-CH4-PORT |
| 45 | IO-CH5-PORT |
| 46 | IO-CH6-PORT |
| 47 | IO-CH7-PORT |
| 48 | IO-CH8-PORT |

### CAN 总线

| Pin | 信号名 |
|-----|---|
| 77 | CAN1_P |
| 78 | CAN1_N |
| 79 | CAN2_P |
| 80 | CAN2_N |

### I2C

| 总线 | SCL Pin | SDA Pin |
|---|---|---|
| GPS1 | 69 | 68 |
| GPS2 | 71 | 70 |
| EXT2 | 67 | 66 |

### SPI EXT1

| Pin | 信号名 |
|-----|---|
| 1 | SCK_EXT1 |
| 2 | MISO_EXT1 |
| 3 | MOSI_EXT1 |
| 4 | CS2_EXT1 |
| 5 | CS1_EXT1 |
| 6 | nSYNC_EXT1 |
| 7 | DRDY1_EXT1 |
| 8 | DRDY2_EXT1 |
| 9 | SPI_nRST |

### SWD 调试（IO 侧）

| Pin | 信号名 |
|-----|---|
| 53 | IO_SWCLK |
| 54 | IO_SWDIO |
| 55 | IO_SWO |
| 56 | IO_USART1_TX_DEBUG |

### FMU 控制 / 状态

| Pin | 信号名 |
|-----|---|
| 10 | ADC3_6V6_PORT |
| 11 | ADC3_3V3_PORT |
| 12 | nARMED_PORT |
| 13 | FMU_RST_REQ_PORT |
| 14 | FMU_BOOTLOADER_PORT |
| 15 | FMU_CAP1_PORT |

### LED

| Pin | 信号名 | 说明 |
|-----|---|---|
| 16 | nLED_BLUE | FMU 蓝灯 |
| 17 | nLED_GREEN | FMU 绿灯 |
| 18 | nLED_RED | FMU 红灯 |
| 74 | nIO_LED_BLUE | IO 蓝灯 |
| 75 | nIO_LED_AMBER | IO 琥珀灯 |

### GPIO / 复位

| Pin | 信号名 |
|-----|---|
| 50 | IO_nRST |
| 51 | IO_SPARE_GPIO2 |
| 52 | IO_SPARE_GPIO1 |

### 未连接（NC）

Pin：**23–32, 34–40, 57, 59, 62, 73**

---

## 修订记录

| 日期 | 说明 |
|---|---|
| 2026-06-25 | 从零一 X9 Core DF17 引脚图提取，约定左上=1、左下=80 |

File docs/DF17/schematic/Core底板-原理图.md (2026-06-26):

# X9 Core 载板原理图（仅双 DF17）

> 自动生成：`python tools/setup_core_carrier_schematic.py`

## 页面

- **Sheet 名称**：`Core_Carrier`
- **标题**：X9 Core 载板 — 双 DF17 80P

## 视图镜像约定

Core 底视（上=80DS，下=80DP）：上排奇数 Pin1,3,…,79（左→右），下排偶数 Pin2,4,…,80（左→右）；四角 Pin1 左上、Pin2 左下、Pin79 右上、Pin80 右下。载板 PCB 为 Top View，相对 Core 底视左右 180° 镜像（载板 Pin1 在符号右上、Pin80 在左下）。载板 DP 配 Core DS（PCB +Y），载板 DS 配 Core DP（PCB −Y）。原理图页面与 Core 引脚图同序：上 J1=80DS、下 J2=80DP；载板标网取自 carrier-80DS/80DP 引脚表（同 Pin 号对接 Core 对面座子）。立创 LCSC 原符号为奇偶分行，使用工程库自定义符号 DF17-*-carrier-mirror。

## 与 Core 资料对照

| Core 底视位置 | Core 座子 | 载板位号 | 载板座子 | PCB |
|---|---|---|---|-----|
| top | 80DS | J1 | DF17(3.0)-80DS-0.5V(57) | -Y |
| bottom | 80DP | J2 | DF17(1.0H)-80DP-0.5V(57) | +Y |

## 连接器

| 位号 | 载板位置 | 载板型号 | 对接 Core |
|---|---|---|---|
| J1 | -Y | DF17(3.0)-80DS-0.5V(57) | 80DP |
| J2 | +Y | DF17(1.0H)-80DP-0.5V(57) | 80DS |

## 引脚网络（按 Pin 编号）

### J1 — DF17(3.0)-80DS-0.5V(57)

| Pin | 网络名 | 类别 |
|-----|---|---|
| 1 | CTS_TELEM3 | UART TELEM3 |
| 2 | VBUS | USB |
| 3 | RTS_TELEM3 | UART TELEM3 |
| 4 | VBUS | USB |
| 5 | RX_TELEM3 | UART TELEM3 |
| 6 | USB_D_N | USB |
| 7 | TX_TELEM3 | UART TELEM3 |
| 8 | USB_D_P | USB |
| 9 | CTS_TELEM2 | UART TELEM2 |
| 10 | GND | 地 |
| 11 | RTS_TELEM2 | UART TELEM2 |
| 12 | BUZZ- | 蜂鸣器 |
| 13 | RX_TELEM2 | UART TELEM2 |
| 14 | SAFETY_SW_LED | 安全开关 |
| 15 | TX_TELEM2 | UART TELEM2 |
| 16 | SAFETY_SW | 安全开关 |
| 17 | CTS_TELEM1 | UART TELEM1 |
| 18 | GND | 地 |
| 19 | RTS_TELEM1 | UART TELEM1 |
| 20 | NC | — |
| 21 | RX_TELEM1 | UART TELEM1 |
| 22 | VDD_5V_HIPOWER_nOC | 电源控制 |
| 23 | TX_TELEM1 | UART TELEM1 |
| 24 | VDD_5V_HIPOWER_nEN | 电源控制 |
| 25 | RX_GPS2 | UART GPS2 |
| 26 | VDD_5V_PERIPH_nOC | 电源控制 |
| 27 | TX_GPS2 | UART GPS2 |
| 28 | VDD_5V_PERIPH_nEN | 电源控制 |
| 29 | RX_GPS1 | UART GPS1 |
| 30 | PPM_IN_PORT | RC |
| 31 | TX_GPS1 | UART GPS1 |
| 32 | RSSI_IN_PORT | RC |
| 33 | RX_EXT2 | UART EXT2 |
| 34 | SBUS_OUTPUT_PORT | RC |
| 35 | TX_EXT2 | UART EXT2 |
| 36 | RX_SBUS_INPUT_PORT | RC |
| 37 | NC | — |
| 38 | GND | 地 |
| 39 | VDD_5V_IN | 电源 |
| 40 | VDD_5V_IN | 电源 |
| 41 | VDD_5V_IN | 电源 |
| 42 | VDD_5V_IN | 电源 |
| 43 | NC | — |
| 44 | GND | 地 |
| 45 | VDD_3V3_OUT | 电源 |
| 46 | ETH_LED | 以太网 |
| 47 | VDD_3V3_OUT | 电源 |
| 48 | GND | 地 |
| 49 | USART3_TX_DEBUG | 调试串口 |
| 50 | ETH_TD2_P | 以太网 |
| 51 | USART3_RX_DEBUG_P | 调试串口 |
| 52 | GND | 地 |
| 53 | FMU_SWDIO | SWD |
| 54 | ETH_TD2_N | 以太网 |
| 55 | FMU_SWCLK | SWD |
| 56 | GND | 地 |
| 57 | FMU_nRST | FMU |
| 58 | ETH_RD2_P | 以太网 |
| 59 | PD15(PH11) | GPIO |
| 60 | GND | 地 |
| 61 | NFC_GPIO | GPIO |
| 62 | ETH_RD2_N | 以太网 |
| 63 | GND | 地 |
| 64 | GND | 地 |
| 65 | FMU_CH1_PROT | PWM |
| 66 | NC | — |
| 67 | FMU_CH2_PROT | PWM |
| 68 | NC | — |
| 69 | FMU_CH3_PROT | PWM |
| 70 | NC | — |
| 71 | FMU_CH4_PROT | PWM |
| 72 | NC | — |
| 73 | FMU_CH5_PROT | PWM |
| 74 | NC | — |
| 75 | FMU_CH6_PROT | PWM |
| 76 | NC | — |
| 77 | FMU_CH7_PROT | PWM |
| 78 | NC | — |
| 79 | FMU_CH8_PROT | PWM |
| 80 | NC | — |

### J2 — DF17(1.0H)-80DP-0.5V(57)

| Pin | 网络名 | 类别 |
|-----|---|---|
| 1 | SCK_EXT1 | SPI EXT1 |
| 2 | CAN2_N | CAN |
| 3 | MISO_EXT1 | SPI EXT1 |
| 4 | CAN2_P | CAN |
| 5 | MOSI_EXT1 | SPI EXT1 |
| 6 | CAN1_N | CAN |
| 7 | CS2_EXT1 | SPI EXT1 |
| 8 | CAN1_P | CAN |
| 9 | CS1_EXT1 | SPI EXT1 |
| 10 | GND | 地 |
| 11 | nSYNC_EXT1 | SPI EXT1 |
| 12 | nIO_LED_AMBER | LED |
| 13 | DRDY1_EXT1 | SPI EXT1 |
| 14 | nIO_LED_BLUE | LED |
| 15 | DRDY2_EXT1 | SPI EXT1 |
| 16 | NC | — |
| 17 | SPI_nRST | SPI EXT1 |
| 18 | GND | 地 |
| 19 | ADC3_6V6_PORT | ADC |
| 20 | SCL_GPS2 | I2C GPS2 |
| 21 | ADC3_3V3_PORT | ADC |
| 22 | SDA_GPS2 | I2C GPS2 |
| 23 | nARMED_PORT | FMU |
| 24 | SCL_GPS1 | I2C GPS1 |
| 25 | FMU_RST_REQ_PORT | FMU |
| 26 | SDA_GPS1 | I2C GPS1 |
| 27 | FMU_BOOTLOADER_PORT | FMU |
| 28 | SCL_EXT2 | I2C EXT2 |
| 29 | FMU_CAP1_PORT | FMU |
| 30 | SDA_EXT2 | I2C EXT2 |
| 31 | nLED_BLUE | LED |
| 32 | nPOWER_IN_C | 电源检测 |
| 33 | nLED_GREEN | LED |
| 34 | nPOWER_IN_B | 电源检测 |
| 35 | nLED_RED | LED |
| 36 | nPOWER_IN_A | 电源检测 |
| 37 | GND | 地 |
| 38 | NC | — |
| 39 | VDD_5V_IN | 电源 |
| 40 | VDD_5V_IN | 电源 |
| 41 | VDD_5V_IN | 电源 |
| 42 | VDD_5V_IN | 电源 |
| 43 | GND | 地 |
| 44 | NC | — |
| 45 | NC | — |
| 46 | VDD_SERVO_IN | 电源 |
| 47 | NC | — |
| 48 | NC | — |
| 49 | NC | — |
| 50 | IO_USART1_TX_DEBUG | 调试串口 |
| 51 | NC | — |
| 52 | IO_SWO | SWD |
| 53 | NC | — |
| 54 | IO_SWDIO | SWD |
| 55 | NC | — |
| 56 | IO_SWCLK | SWD |
| 57 | NC | — |
| 58 | IO_SPARE_GPIO1 | GPIO |
| 59 | NC | — |
| 60 | IO_SPARE_GPIO2 | GPIO |
| 61 | NC | — |
| 62 | IO_nRST | IO |
| 63 | NC | — |
| 64 | GND | 地 |
| 65 | GND | 地 |
| 66 | IO-CH8-PORT | PWM/IO |
| 67 | NC | — |
| 68 | IO-CH7-PORT | PWM/IO |
| 69 | NC | — |
| 70 | IO-CH6-PORT | PWM/IO |
| 71 | NC | — |
| 72 | IO-CH5-PORT | PWM/IO |
| 73 | NC | — |
| 74 | IO-CH4-PORT | PWM/IO |
| 75 | NC | — |
| 76 | IO-CH3-PORT | PWM/IO |
| 77 | NC | — |
| 78 | IO-CH2-PORT | PWM/IO |
| 79 | NC | — |
| 80 | IO-CH1-PORT | PWM/IO |

## EDA 操作步骤

1. 删除多余原理图页，仅保留一页并重命名为 Core_Carrier
2. 在工程库创建载板镜像符号（见 tools/create_df17_carrier_mirror_symbols.py）
3. 放置 J1=80DS（上）、J2=80DP（下），与 Core 官方引脚图同序；标网用 carrier-80DS/80DP 引脚表
4. LCSC 标准符号：J1(上 DS) rotation=90 mirror=true，J2(下 DP) rotation=270 mirror=true
5. （或 carrier-mirror 自定义符号：J1 rotation=0，J2 rotation=180）
6. Pin1 位于 J1 右上；J2 相对 J1 上下镜像（Pin1 左下）
7. PCB 贴装：+Y 仍为 80DP、−Y 仍为 80DS（与原理图上下顺序相反，属正常）
8. NC 引脚加 No Connect；GND 引脚后续统一接 GND 符号（手动）
9. PCB 导入 carrier-pcb.dxf 后替换 DXF 参考焊盘为官方封装

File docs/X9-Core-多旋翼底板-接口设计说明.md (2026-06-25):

# X9 Core 多旋翼飞控底板 — 接口需求与引脚分配

> 适配文档：[零一飞行 X9 系列飞控说明书](https://docs.01aero.cn/docs/JfRLkT8E)  
> 目标机型：多旋翼（ArduCopter）  
> EDA 工具：嘉立创 EasyEDA  
> 文档版本：v0.1 · 2026-06-25

---

## 1. 设计目标

为 **X9 Core**（无自带接口板）设计一块多旋翼载板，实现：

1. 通过底部 **DF17** 连接器与 X9 Core 可靠对接（机械 + 电气）
2. 复用 X9 Cube 接口板的 **连接器型号与线序习惯**，降低线束与调试成本
3. 满足典型多旋翼外设：电源、GPS、数传、遥控、CAN 设备、PWM 电调
4. 工作电压 **4.5 V–5.4 V**（飞控供电），外设 5 V 由载板电源切换模块分配

### 1.1 X9 Core 关键参数（摘自官方文档）

| 项目 | 规格 |
|---|---|
| 主 MCU | STM32H753 |
| IO MCU | STM32F103 |
| IMU | IIM42652 ×3（三余度） |
| 气压计 | ICP-20100×2 或 BMP581+SPL07 |
| 磁罗盘 | RM3100（内置） |
| 工作电压 | 4.5 V–5.4 V |
| 尺寸 | 38.8 × 38.8 × 26.5 mm |
| 重量 | 72 g |
| PWM 能力 | 14 路（经 DF17 引出） |
| 机型 | 直升机、多旋翼、固定翼、VTOL、车、船 |

---

## 2. 机械与连接器

### 2.1 DF17 对接（载板侧）

- 官方说明：文档中 **DF17 引脚图、尺寸图为飞控底部视图**；设计载板时 **连接器方向与丝印需镜像反向**。
- 载板应预留：
  - DF17 母座（或按零一提供的推荐料号选型）
  - X9 Core 安装高度与减震/支撑结构（参考 Cube 系列载板做法：四角支撑 + 中央 DF17）
  - 散热与 IMU 减震：Core 内置减震，载板 **不得** 对飞控本体施加额外刚性约束

> **Pinout 已录入**：[80DS](DF17/DF17-80DS-pinout.md)、[80DP](DF17/DF17-80DP-pinout.md)。**待补充**：封装尺寸图 DXF（购买 X9 Core 用户可向厂商索取底板设计资源）。

### 2.2 对外连接器型号（与 X9 Cube 一致）

| 接口 | 连接器型号 | 针数 | 载板角色 |
|---|---|---|---|
| POWER1 / POWER2 | Molex 5055650601 | 6 | 电源输入（接 OnePMU 或等效 CAN 电源模块） |
| TELEM1 / TELEM2 / GPS1 / GPS2 / CAN1 / CAN2 / SBUS / I2C / ETH / AUX 等 | JST-GH 1.25 mm | 4 | 信号与外设 |
| USB | Type-C 或 GH 扩展 | — | 地面站配置 / 刷固件 |

---

## 3. 电源架构

### 3.1 电源切换模块（载板必须实现）

官方提供电源切换模块参考设计，载板需实现 **双路 Brick 输入 + USB + 外设配电**：

| 模块信号序号 | 信号名 | 载板连接 |
|---|---|---|
| 1–3 | nPOWER_IN_A/B/C | → X9 Core 同名脚（电源选择逻辑） |
| 4–5 | VBUS | ← USB Type-C |
| 6–7 | VDD_5V_BRICK2 | ← POWER2（Molex 6pin） |
| 8–9 | VDD_5V_BRICK1 | ← POWER1（Molex 6pin） |
| 10 | VDD_5V_IN | → X9 Core 系统 5 V 输入 |
| 11 | VDD_5V_HIPOWER | → 高耗电外设接口（如部分舵机总线，多旋翼可预留） |
| 12 | VDD_5V_PERIPH | → 普通外设 5 V（GPS、数传、接收机等） |
| 13 | FMU_VDD_3V3 | 飞控上拉参考 |
| 14–15 | GND | 地 |
| 16 | VDD_5V_PERIPH_nEN | ↔ X9 Core 外设电源使能 |
| 17 | VDD_5V_PERIPH_nOC | ↔ X9 Core 外设过流反馈 |
| 18 | VDD_5V_HIPOWER_nEN | ↔ X9 Core 高耗使能 |
| 19 | VDD_5V_HIPOWER_nOC | ↔ X9 Core 高耗过流反馈 |

### 3.2 多旋翼电源设计建议

| 路径 | 建议 |
|---|---|
| 主供电 | POWER1 接 **OnePMU / DroneCAN 电源模块**（推荐），POWER2 作冗余或第二电池监测 |
| 飞控供电 | 经切换模块输出 **VDD_5V_IN**，保证 4.5–5.4 V |
| 外设 5 V | GPS、数传、接收机走 **VDD_5V_PERIPH**，总电流按器件手册核算 |
| 电调供电 | **大电流动力电不经过载板 5 V 轨**；PWM 仅信号，ESC BEC 或独立 UBEC 供舵机/外设时注意共地 |
| USB | 地面调试时 VBUS 参与供电切换，原理图按官方参考实现防反灌 |

---

## 4. 串口映射（ArduPilot SERIAL 约定）

载板丝印与参数配置须与下表一致（摘自官方文档）：

| SERIAL | 载板丝印 | MCU UART | DMA | 多旋翼典型用途 |
|---|---|---|-----|---|
| SERIAL0 | USB | OTG1 | — | 地面站 / 刷固件 |
| SERIAL1 | TELEM1 | UART7 | 已启用 | 数传（OneDLink / OneVDLink / 三方） |
| SERIAL2 | TELEM2 | UART5 | 已启用 | 备用数传 / 伴飞计算机 |
| SERIAL3 | GPS1 | USART1 | 已启用 | 主 GPS（建议接含安全开关/蜂鸣器/LED 的 GPS 座） |
| SERIAL4 | GPS2 | UART8 | 已启用 | 副 GPS / RTK 漫游 |
| SERIAL5 | TELEM3 | USART2 | 已启用 | RS232 数传或 MAVLink 设备 |
| SERIAL6 | UART4 | UART4 | 已启用 | 扩展串口（测距、4G 等） |
| SERIAL7 | DEBUG | USART3 | 已启用 | 调试（生产可不外接） |
| SERIAL8 | SLCAN | USB OTG | — | CAN 调试（通常不占用载板座子） |

### 4.1 JST-GH 4pin 串口线序（与 Pixhawk 系习惯对齐）

载板对外座子建议统一：

```text
Pin1  VCC  (5 V，来自 VDD_5V_PERIPH，经座子侧可选串阻/保险)
Pin2  TX   (飞控 → 外设 RX)
Pin3  RX   (飞控 ← 外设 TX)
Pin4  GND
```

TELEM3（USART2）若接 RS232 设备，载板侧应放 **TTL↔RS232 电平转换** 或单独 RS232 座子，勿与 TTL 座子混用。

---

## 5. 多旋翼接口功能分配

### 5.1 载板对外接口清单（推荐）

| 序号 | 载板接口 | 数量 | 优先级 | 说明 |
|---|---|---|---|---|
| P1 | POWER1 | 1 | 必须 | 主电源 + CAN PMU |
| P2 | POWER2 | 1 | 推荐 | 冗余电源监测 |
| P3 | GPS1 | 1 | 必须 | 主定位；建议兼容零一 GPS&Safety 线序 |
| P4 | TELEM1 | 1 | 必须 | 主数传 |
| P5 | SBUS IN | 1 | 必须 | 遥控接收机（或预留 CRSF 需确认硬件支持） |
| P6 | CAN1 | 1 | 推荐 | DroneCAN ESC / 罗盘 / 气压计 |
| P7 | CAN2 | 1 | 可选 | 第二 CAN 总线 |
| P8 | M1–M8 | 8 | 按机型 | 四轴用 4 路，六轴 6 路，八轴 8 路 |
| P9 | M9–M14 | 6 | 可选 | 扩展电机或 AUX PWM |
| P10 | TELEM2 | 1 | 可选 | 第二数传 |
| P11 | GPS2 | 1 | 可选 | 双 GPS / RTK |
| P12 | I2C | 1 | 可选 | 外置传感器 |
| P13 | USB Type-C | 1 | 必须 | 调参刷机 |
| P14 | ETH | 1 | 可选 | 网口相机 / 伴飞 |
| P15 | AD&IO | 1 | 可选 | 模拟电流计 / Bootloader |
| P16 | DSM/PPM IN | 1 | 可选 | 替代 SBUS 的接收机协议 |

X9 最多 **14 路 PWM**；四旋翼占用 M1–M4，六旋翼 M1–M6，八旋翼 M1–M8，余量可作蜂鸣器、相机快门等 AUX。

### 5.2 电机 PWM 通道与 ArduCopter 映射

ArduCopter 默认电机顺序与 **物理安装位置** 相关，载板丝印 **M1–Mn 应一一对应飞控 PWM 输出编号**（经 DF17 映射后的逻辑通道），地面站 Motor Test 逐路验证。

**四旋翼（Quad X）推荐丝印与功能：**

| 载板丝印 | ArduCopter 电机号 | 典型位置 | 备注 |
|---|---|---|---|
| M1 | Motor 1 | 右前 | 方向以桨叶实测为准 |
| M2 | Motor 2 | 左后 | |
| M3 | Motor 3 | 左前 | |
| M4 | Motor 4 | 右后 | |
| M5–M8 | AUX / 未用 | — | 预留 |

**六旋翼 / 八旋翼**：按 `FRAME_CLASS` 扩展 M1–M6 或 M1–M8；下载固件时选择 **ArduCopter**，机架类型在地面站配置。

### 5.3 PWM 电气特性

- 官方说明（X6 同系列）：**M1–M14 支持 DShot**（部分高端通道支持双向 DShot，以 X9 固件与 hwdef 为准）。
- 载板 PWM 走线：
  - 信号线短、等长优先；远离电源与大电流回路
  - 每路飞控侧近端可选 **33 Ω–100 Ω** 串联阻尼
  - 电调信号地与电源地 **单点共地** 于载板电源入口

---

## 6. CAN 总线

| 项目 | 建议 |
|---|---|
| 拓扑 | CAN1 为主总线，终端电阻 **120 Ω** 在总线两端各一（载板可在 CAN1 座子旁跳线选择是否内置终端） |
| 用途 | DroneCAN 电调、OnePMU、OneASP 空速计、OneRTK 等 |
| 线序 | 遵循 DroneCAN：CAN_H、CAN_L、GND、5 V（按零一线材定义） |
| 速率 | 默认 1 Mbps；长缆/多节点按 ArduPilot 文档降速测试 |

---

## 7. 遥控与 GPS

### 7.1 SBUS IN

- 接 4pin GH：信号 + 5 V + GND（接收机供电从 VDD_5V_PERIPH）
- 注意 SBUS 为 **反相串口**，飞控硬件已处理；载板勿再反相

### 7.2 GPS1（推荐集成座）

多旋翼强烈建议使用带 **安全开关、蜂鸣器、RGB LED** 的 GPS 座，便于解锁逻辑与状态指示。线序对齐零一 **GPS&Safety** 或 Pixhawk 兼容座。

### 7.3 内置罗盘

X9 Core 已内置 **RM3100**，外接 GPS 罗盘模块时须在地面站设置 `COMPASS_USE` / `COMPASS_PRIO` 避免冲突；载板无额外动作，调试文档中说明即可。

---

## 8. 固件与调试检查单

| 步骤 | 内容 |
|---|---|
| 1 | 刷入零一提供的 **X9 系列 ArduCopter** 固件（[资源库](https://pan.01aero.cn/s/mYhv零一飞行资源库/X9系列飞控/ArduPilot固件)） |
| 2 | Mission Planner / QGC：加速度计、罗盘、遥控、ESC 校准 |
| 3 | 确认 `SERIAL1_PROTOCOL` 等数传参数与 TELEM1 一致 |
| 4 | Motor Test：M1–M4 与桨叶位置、转向一致 |
| 5 | DroneCAN：若用 CAN 电调，确认 `CAN_D1_PROTOCOL=1` 及节点发现 |
| 6 | 解锁前：GPS 定位、罗盘健康、电源监测（Battery Monitor）正常 |

---

## 9. EasyEDA 原理图分区建议

便于后续画原理图，建议工程按 **Sheet** 划分：

```text
01_Power_Switching     电源切换 + POWER1/2 + USB-C
02_DF17_Interface      DF17 插座及至各子系统的网络标签
03_PWM_Outputs         M1–M14 输出 + GH 座子
04_Telemetry_GPS       TELEM1/2/3, GPS1/2
05_CAN_Bus             CAN1/2 + 终端电阻跳线
06_RC_SBUS             SBUS / DSM-PPM
07_Misc                I2C, ETH, AD&IO, SPI, LED/按键
08_Mechanical          板框、安装孔、DF17 定位（导入官方 DXF 后补）
```

### 9.1 设计规则（DRA）

| 项目 | 建议 |
|---|---|
| 板层 | 4 层：Top 信号 / GND / PWR / Bottom 信号 |
| 线宽 | 5 V 主供电 ≥ 0.5 mm（按电流核算）；PWM ≥ 0.2 mm |
| 过孔 | 电源地密集过孔围栏 |
| 丝印 | 每个 GH 座标注：接口名 + Pin1 方向 + SERIAL 号 |

---

## 10. 待办与风险

| 项 | 状态 | 说明 |
|----|---|---|
| DF17 完整 80pin 定义 | 已完成 | 见 [80DS](DF17/DF17-80DS-pinout.md)、[80DP](DF17/DF17-80DP-pinout.md)；封装 DXF 仍待索取 |
| 电源切换原理图 | 待画 | 严格对照官方「电源切换模块」原理图 |
| TELEM3 RS232 电平 | 待确认 | 是否板载 MAX3232 或仅 TTL |
| DShot 双向 | 待确认 | 以 X9 hwdef 为准，影响 M 通道布局 |
| 板厚与结构 | 待确认 | 与机身安装空间、减震方案联调 |

---

## 11. 参考链接

- [X9 系列飞控说明书](https://docs.01aero.cn/docs/JfRLkT8E)
- [ArduPilot 固件（零一盘）](https://pan.01aero.cn/s/mYhv零一飞行资源库/X9系列飞控/ArduPilot固件)
- [Mission Planner](https://firmware.ardupilot.org/Tools/MissionPlanner)
- [QGroundControl](https://github.com/mavlink/qgroundcontrol/releases)

---

## 修订记录

| 版本 | 日期 | 说明 |
|---|---|---|
| v0.1 | 2026-06-25 | 初版：多旋翼接口需求与引脚分配 |

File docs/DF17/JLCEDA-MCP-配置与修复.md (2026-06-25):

# JLCEDA MCP 配置与修复

## 链路

```
嘉立创 EDA (MCP Bridge)  ←ws→  Cursor (JLCEDA MCP Hub)  ←MCP→  Agent
```

| 侧 | 地址 |
|----|---|
| EDA Bridge | `ws://127.0.0.1:8760/bridge/ws` |
| HTTP MCP（可选） | `http://127.0.0.1:7655/mcp` |

## 正常配置

### Cursor

1. 安装扩展 **JLCEDA MCP Hub**（`chengbin.jlceda-mcp-hub`）
2. Settings 中确认：
   - `jlcMcpServer.port`: **8760**
   - `jlcMcpServer.httpPort`: **7655**
3. **Settings → MCP** → `jlceda-mcp-hub` 应为 **Connected**

### 嘉立创 EDA

1. 只启用 **MCP Bridge (Lion)**，禁用 Run API Gateway / 重复 Bridge
2. **MCP Bridge → 连接设置** → `ws://127.0.0.1:8760/bridge/ws`
3. 必须在 **原理图或 PCB 页** 才能连接

## 根因（Connection closed）

Cursor 下 Hub 扩展用 `Cursor.exe` 启动 MCP 运行时，导致参数 `--storage-directory` 等被当成 Electron 开关，进程秒退。

**已修复**：`getRuntimeCommand()` 改为使用 Cursor 自带 `node.exe`。

扩展路径：

```
%USERPROFILE%\.cursor\extensions\chengbin.jlceda-mcp-hub-1.5.4-universal\out\extension.js
```

> 扩展升级后若复发，重新应用该 patch，或运行下方手动启动脚本。

## 手动启动（备用）

```powershell
powershell -ExecutionPolicy Bypass -File G:\soft\01飞控\tools\start_jlceda_mcp.ps1
```

验证：

```powershell
netstat -ano | findstr 8760
```

应看到 `LISTENING`。

## 8765 端口冲突

GCS COM bridge（`G:\soft\GCS\legacy\web\tools\com-bridge\server.py`）占用 **8765**，因此 Hub 端口改为 **8760**。不要用 8765，除非先停 GCS bridge。

## 验收

1. `netstat` 见 8760 **LISTENING**
2. Cursor Hub：**EDA 连接 → 桥接客户端已连接**
3. EDA：**桥接连接 → 已连接**（非「等待 stdio 启动」）

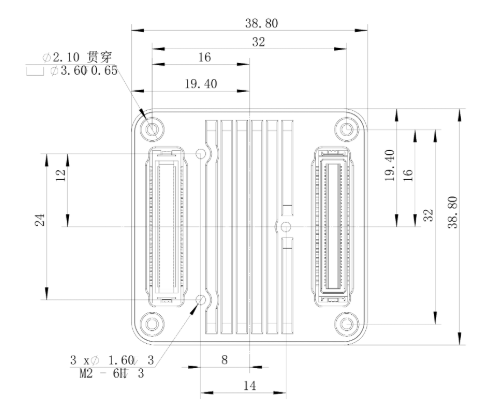
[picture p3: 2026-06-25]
docs/DF17/cad/X9-Core-bottom-reference.png

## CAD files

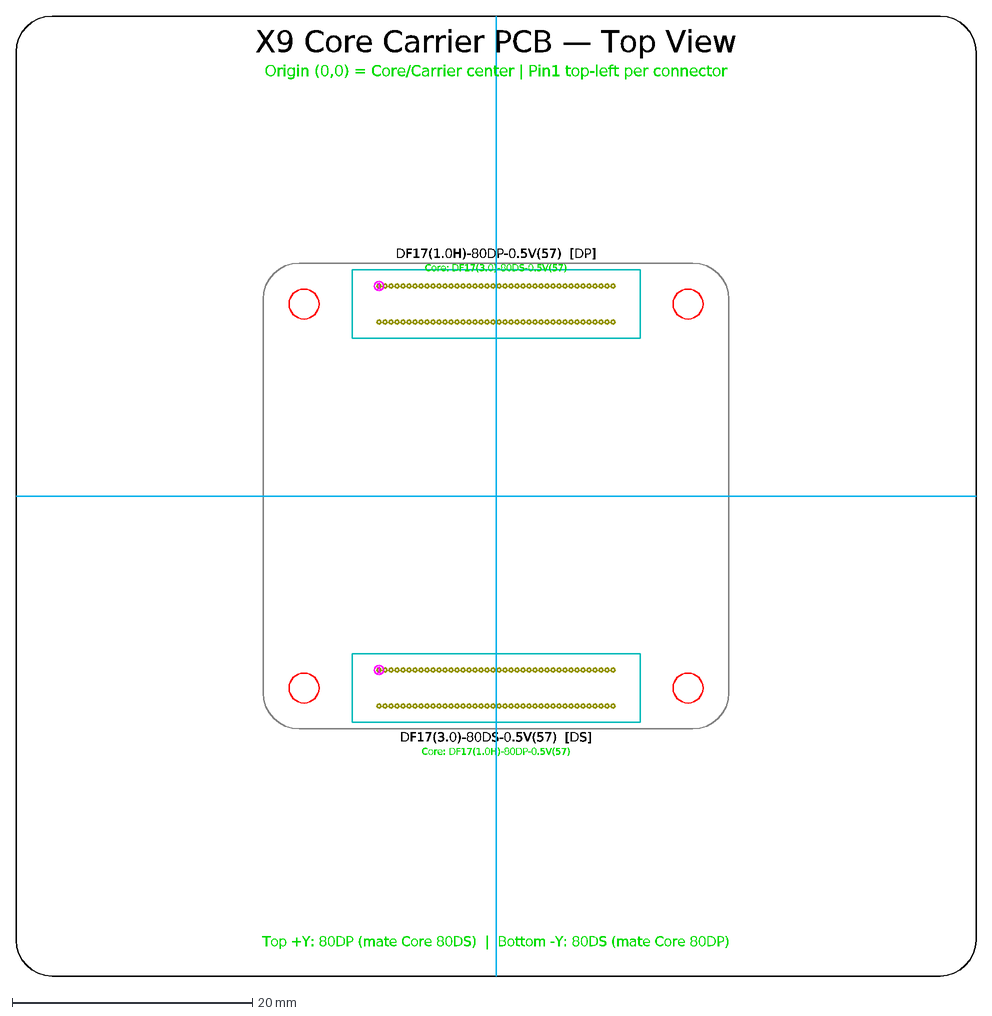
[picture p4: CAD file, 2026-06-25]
docs/DF17/cad/carrier-pcb.dxf
1
DF17(1.0H)-80DP-0.5V(57) [DP]
Core: DF17(3.0)-80DS-0.5V(57)
DF17(3.0)-80DS-0.5V(57) [DS]
Core: DF17(1.0H)-80DP-0.5V(57)
X9 Core Carrier PCB — Top View
Origin (0,0) = Core/Carrier center | Pin1 top-left per connector
Top +Y: 80DP (mate Core 80DS) | Bottom -Y: 80DS (mate Core 80DP)

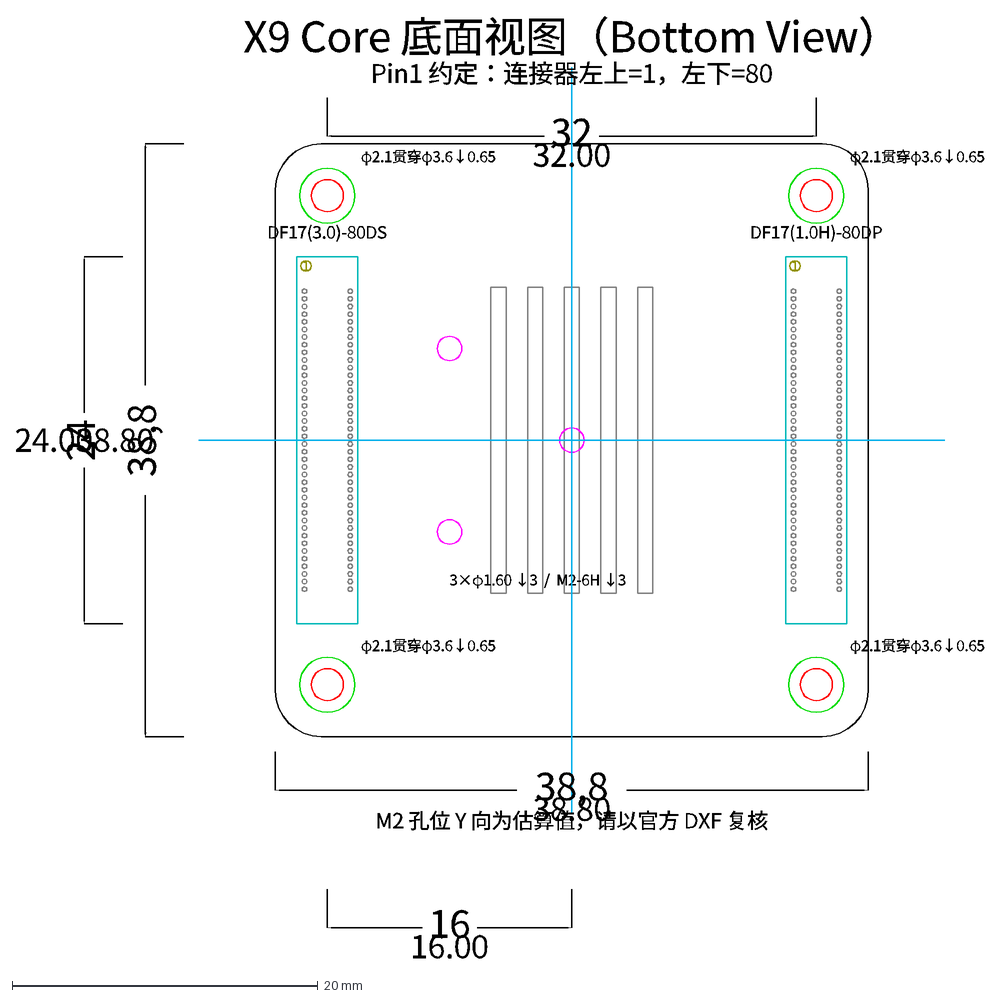
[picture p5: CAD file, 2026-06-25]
docs/DF17/cad/X9-Core-bottom.dxf
φ2.1贯穿φ3.6↓0.65
DF17(3.0)-80DS
1
DF17(1.0H)-80DP
3×φ1.60 ↓3 / M2-6H ↓3
X9 Core 底面视图（Bottom View）
Pin1 约定：连接器左上=1，左下=80
M2 孔位 Y 向为估算值，请以官方 DXF 复核
38,8
38.80
32
32.00
24
24.00
16
16.00

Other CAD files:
docs/DF17/cad/X9-Core-bottom.dwg

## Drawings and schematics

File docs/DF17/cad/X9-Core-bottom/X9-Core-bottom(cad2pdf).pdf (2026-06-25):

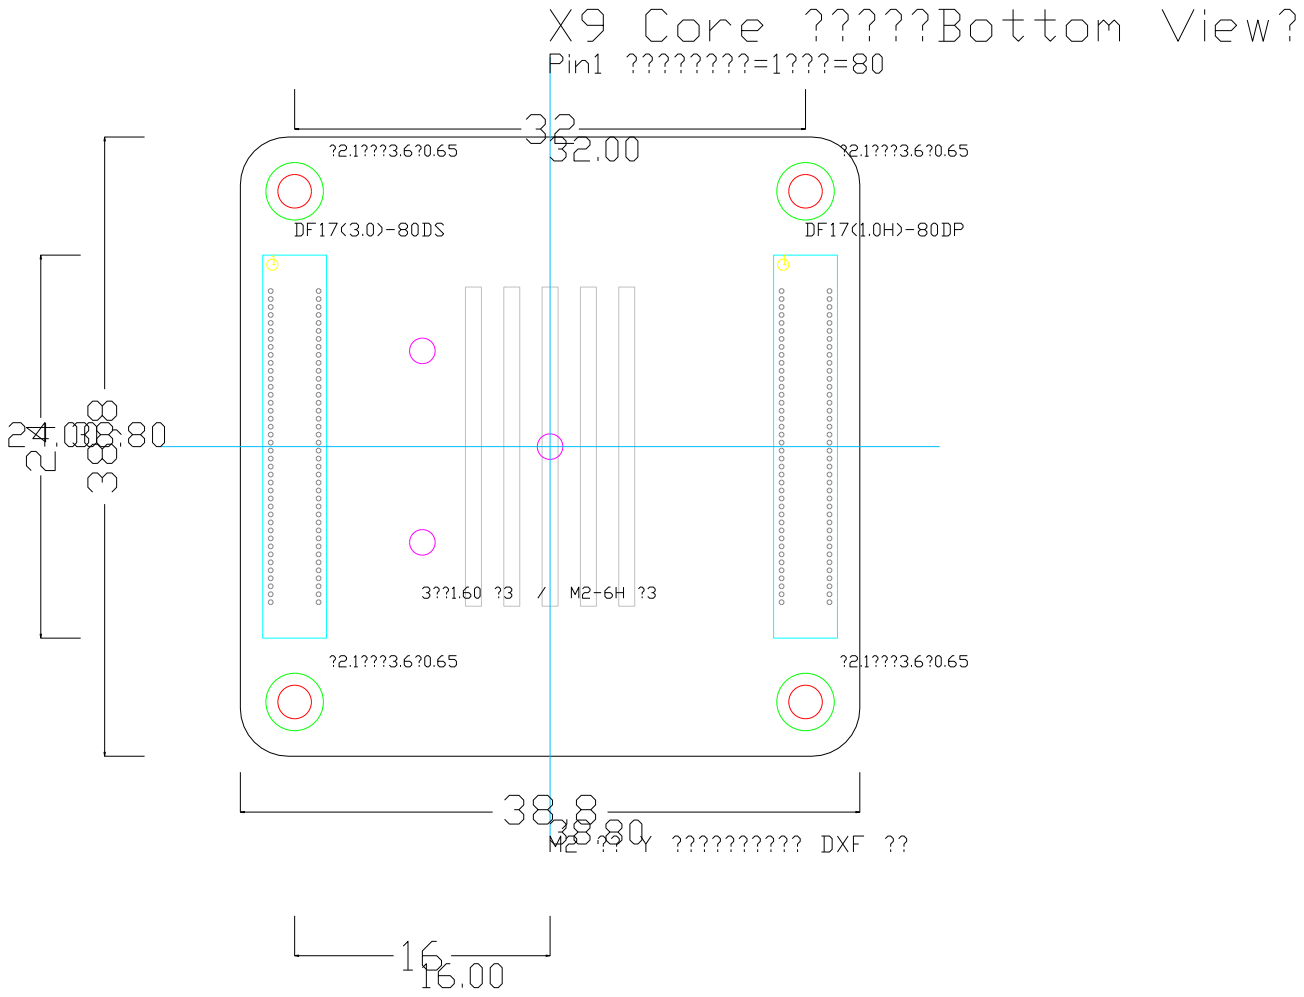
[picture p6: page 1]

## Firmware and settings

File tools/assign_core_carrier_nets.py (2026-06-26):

#!/usr/bin/env python3
"""为 Core 载板原理图 U1/U2 连接器批量添加引脚网络（经 JLCEDA MCP HTTP）。

每个信号 Pin：
  1. 从引脚沿竖直方向拉导线，并用 Wire.create(line, net) 赋网络名（嘉立创可见）
  2. createNetLabel 在当前 MCP 下不生效，已弃用
  - rotation=90：向下 (y + stub)
  - rotation=270：向上 (y - stub)
  - stub 同排 **统一长度**：按该排最长网络名 × CHAR_PITCH × scale + MARGIN
  - 默认包含 GND；NC 默认跳过（用 assign_nc_no_connect.py 删线并挂 No Connect）
  - 若仍需 NC 短线标 net 名：加 --wire-nc

用法：
  python3 tools/assign_core_carrier_nets.py --replace --designator U1
  python3 tools/assign_core_carrier_nets.py --replace --safe-stub   # 仅 8mil 短线
  python3 tools/assign_nc_no_connect.py                             # NC 引脚 No Connect
"""

from __future__ import annotations

import argparse
import json
import sys
import urllib.error
import urllib.request
from pathlib import Path

ROOT = Path(__file__).resolve().parents[1]
SPEC_PATH = ROOT / "docs" / "DF17" / "schematic" / "core-carrier-schematic-spec.json"
MCP_URL = "http://127.0.0.1:7655/mcp"

PART_NUMBERS = {
    "DF17(1.0H)-80DP-0.5V(57)",
    "DF17(3.0)-80DS-0.5V(57)",
    "DF17(3.0H)-80DS-0.5V(57)",
}

NET_SOURCE_PART = {
    "DF17(1.0H)-80DP-0.5V(57)": "DF17(1.0H)-80DP-0.5V(57)",
    "DF17(3.0)-80DS-0.5V(57)": "DF17(3.0)-80DS-0.5V(57)",
    "DF17(3.0H)-80DS-0.5V(57)": "DF17(3.0)-80DS-0.5V(57)",
}

SIGNAL_PIN_MAX = 80
CHAR_PITCH = 12
MARGIN = 20
MIN_STUB = 40
SAFE_STUB = 8
STUB_SCALE = 1 / 3  # 导线长度 = 适应最长网络名 × 此比例（当前 1/3）
COORD_TOL = 1.0
REGION_PAD = 30
REGION_PAD_STUB = 320

TOP_ROTATION = 90
BOTTOM_ROTATION = 270


def mcp_call(tool: str, arguments: dict, req_id: int = 1) -> dict:
    payload = {
        "jsonrpc": "2.0",
        "id": req_id,
        "method": "tools/call",
        "params": {"name": tool, "arguments": arguments},
    }
    req = urllib.request.Request(
        MCP_URL,
        data=json.dumps(payload).encode(),
        headers={"Content-Type": "application/json"},
    )
    with urllib.request.urlopen(req, timeout=180) as resp:
        body = json.load(resp)
    if "error" in body:
        raise RuntimeError(body["error"].get("message", str(body["error"])))
    return body["result"]


def api_invoke(api_full_name: str, args: list, req_id: int, timeout_ms: int = 120_000):
    result = mcp_call(
        "api_invoke",
        {"apiFullName": api_full_name, "args": args, "timeoutMs": timeout_ms},
        req_id,
    )
    text = result["content"][0]["text"]
    data = json.loads(text)
    if "error" in data:
        raise RuntimeError(f"{api_full_name}: {data['error']}")
    return data.get("result", data)


def coords_near(ax: float, ay: float, bx: float, by: float, tol: float = COORD_TOL) -> bool:
    return abs(ax - bx) <= tol and abs(ay - by) <= tol


def stub_for_net(
    net: str,
    char_pitch: int,
    margin: int,
    long_stub: bool,
    stub_scale: float,
) -> int:
    if not long_stub:
        return SAFE_STUB
    full = max(MIN_STUB, len(net) * char_pitch + margin)
    return max(SAFE_STUB, int(full * stub_scale))


def max_stub_for_rotation(
    pin_nets: dict[str, str],
    pin_by_num: dict[str, dict],
    rotation: int,
    char_pitch: int,
    margin: int,
    override: int | None,
    long_stub: bool,
    stub_scale: float,
    *,
    wire_gnd: bool,
    wire_nc: bool,
) -> int:
    if override is not None:
        return override
    stubs: list[int] = []
    for pin_num, net in pin_nets.items():
        if not net:
            continue
        if net == "NC" and not wire_nc:
            continue
        if net == "GND" and not wire_gnd:
            continue
        pin = pin_by_num.get(pin_num)
        if not pin or pin.get("rotation") != rotation:
            continue
        stubs.append(stub_for_net(net, char_pitch, margin, long_stub, stub_scale))
    if not stubs:
        return SAFE_STUB if not long_stub else max(SAFE_STUB, int(MIN_STUB * stub_scale))
    return max(stubs)


def wire_line_pin_direction(
    x: float,
    y: float,
    rotation: int,
    stub: int,
    flip: bool = False,
) -> list[float]:
    """沿引脚朝外竖直直线：rotation=90 向下，rotation=270 向上。"""
    if rotation == TOP_ROTATION:
        dy = stub if not flip else -stub
        return [x, y, x, y + dy]
    if rotation == BOTTOM_ROTATION:
        dy = -stub if not flip else stub
        return [x, y, x, y + dy]
    if rotation == 0:
        return [x, y, x + stub, y]
    if rotation == 180:
        return [x, y, x - stub, y]
    dy = -stub if not flip else stub
    return [x, y, x, y + dy]


def load_spec() -> dict:
    return json.loads(SPEC_PATH.read_text(encoding="utf-8"))


PART_ALIASES: dict[str, str] = {
    "DF17(3.0H)-80DS-0.5V(57)": "DF17(3.0)-80DS-0.5V(57)",
}


def canonical_part(part: str) -> str:
    return PART_ALIASES.get(part, part)


def part_from_component(comp: dict) -> str | None:
    for key in ("schematicSubPartName", "componentSymbolName", "componentValue", "componentName"):
        value = comp.get(key) or ""
        for part in PART_NUMBERS:
            if part in value:
                return canonical_part(part)
    return None


def build_net_maps(spec: dict, components: list[dict]) -> dict[str, dict[str, str]]:
    part_to_pins: dict[str, dict[str, str]] = {}
    for conn in spec["connectors"]:
        part = conn["part_number"]
        source = NET_SOURCE_PART.get(part, part)
        if source in part_to_pins:
            continue
        src_conn = next((c for c in spec["connectors"] if c["part_number"] == source), conn)
        part_to_pins[source] = {
            str(p["pin"]): p["net"] for p in src_conn["pins"] if p["pin"] <= SIGNAL_PIN_MAX
        }
    for part, pin_map in list(part_to_pins.items()):
        part_to_pins[canonical_part(part)] = pin_map

    maps: dict[str, dict[str, str]] = {}
    for comp in components:
        part = part_from_component(comp)
        designator = comp.get("componentDesignator")
        if not part or not designator:
            continue
        pin_map = part_to_pins.get(part) or part_to_pins.get(canonical_part(part))
        if not pin_map:
            continue
        maps[designator] = pin_map
        kind = "DS" if "80DS" in part else "DP"
        pin1 = pin_map.get("1", "")
        if kind == "DS" and pin1 in ("SCK_EXT1", "CAN2_N", "MISO_EXT1"):
            print(
                f"WARN {designator}: DS 座子 Pin1={pin1} 像 Core DS 表，载板 DS 应标 Core DP 网络",
                file=sys.stderr,
            )
        if kind == "DP" and pin1 in ("CTS_TELEM3", "VBUS", "RX_TELEM3"):
            print(
                f"WARN {designator}: DP 座子 Pin1={pin1} 像 Core DP 表，载板 DP 应标 Core DS 网络",
                file=sys.stderr,
            )
    return maps


def read_schematic_components(req_id: int) -> list[dict]:
    result = mcp_call("schematic_read", {}, req_id)
    snap = json.loads(json.loads(result["content"][0]["text"])["schematicCircuitSnapshot"])
    return snap["components"]


def pin_bbox(
    pins: list[dict],
    stub_top: int,
    stub_bottom: int,
    *,
    tight: bool = False,
) -> tuple[int, int, int, int]:
    signal = [p for p in pins if p["pinNumber"].isdigit() and int(p["pinNumber"]) <= SIGNAL_PIN_MAX]
    xs = [p["x"] for p in signal]
    ys = [p["y"] for p in signal]
    pad = max(stub_top, stub_bottom) + REGION_PAD if tight else max(stub_top, stub_bottom, REGION_PAD_STUB)
    return (
        int(min(xs) - REGION_PAD - pad),
        int(max(xs) + REGION_PAD + pad),
        int(min(ys) - REGION_PAD - pad),
        int(max(ys) + REGION_PAD + pad),
    )


def wire_in_bbox(wire: dict, left: int, right: int, top: int, bottom: int) -> bool:
    line = wire.get("line") or []
    if not line:
        return False
    segments = line if isinstance(line[0], list) else [line]
    for seg in segments:
        if len(seg) < 4:
            continue
        xs = seg[0::2]
        ys = seg[1::2]
        if max(xs) >= left and min(xs) <= right and max(ys) >= top and min(ys) <= bottom:
            return True
    return False


def normalize_line(line: list) -> list[float]:
    if line and isinstance(line[0], list):
        return list(line[0])
    return list(line)


def wire_length(line: list[float]) -> float:
    x1, y1, x2, y2 = line[:4]
    return abs(x2 - x1) if abs(y2 - y1) < abs(x2 - x1) else abs(y2 - y1)


def wire_at_pin(wires: list[dict], pin: dict) -> dict | None:
    px, py = pin["x"], pin["y"]
    for wire in wires:
        line = normalize_line(wire.get("line") or [])
        if len(line) < 4:
            continue
        if coords_near(line[0], line[1], px, py) or coords_near(line[2], line[3], px, py):
            return wire
    return None


def delete_all_wires(req_id: int) -> int:
    deleted = 0
    while True:
        wires = api_invoke("eda.sch_PrimitiveWire.getAll", [], req_id)
        req_id += 1
        if not isinstance(wires, list) or not wires:
            break
        ids = [w["primitiveId"] for w in wires]
        for start in range(0, len(ids), 50):
            batch = ids[start : start + 50]
            if batch:
                api_invoke("eda.sch_PrimitiveWire.delete", [batch], req_id)
                req_id += 1
                deleted += len(batch)
        if len(wires) < 120:
            break
    print(f"purged {deleted} wires total")
    return req_id


def delete_wires_near_component(
    pins: list[dict],
    req_id: int,
    dry_run: bool,
    stub_top: int,
    stub_bottom: int,
) -> tuple[int, int]:
    left, right, top, bottom = pin_bbox(pins, stub_top, stub_bottom, tight=True)
    wires = api_invoke("eda.sch_PrimitiveWire.getAll", [], req_id)
    req_id += 1
    if not isinstance(wires, list):
        wires = []
    to_delete = [w["primitiveId"] for w in wires if wire_in_bbox(w, left, right, top, bottom)]
    if dry_run:
        print(f"  would delete {len(to_delete)} wires in bbox ({left},{top})-({right},{bottom})")
        return req_id, len(to_delete)
    for start in range(0, len(to_delete), 50):
        batch = to_delete[start : start + 50]
        if batch:
            api_invoke("eda.sch_PrimitiveWire.delete", [batch], req_id)
            req_id += 1
    return req_id, len(to_delete)


def assign_nets(
    dry_run: bool = False,
    only: str | None = None,
    replace: bool = False,
    char_pitch: int = CHAR_PITCH,
    margin: int = MARGIN,
    stub_top: int | None = None,
    stub_bottom: int | None = None,
    flip: bool = False,
    long_stub: bool = True,
    purge_all_wires: bool = False,
    stub_scale: float = STUB_SCALE,
    wire_gnd: bool = True,
    wire_nc: bool = False,
) -> None:
    spec = load_spec()
    components = read_schematic_components(10)
    net_maps = build_net_maps(spec, components)
    by_designator = {c["componentDesignator"]: c for c in components}
    req_id = 100

    if purge_all_wires and not dry_run:
        req_id = delete_all_wires(req_id)
        print("purged all wires on page")

    for designator, pin_nets in sorted(net_maps.items()):
        if only and designator != only:
            continue
        comp = by_designator.get(designator)
        if not comp:
            print(f"SKIP {designator}: 原理图中未找到该位号", file=sys.stderr)
            continue

        primitive_id = comp["componentInstanceId"]
        pins = api_invoke(
            "eda.sch_PrimitiveComponent.getAllPinsByPrimitiveId",
            [primitive_id],
            req_id,
        )
        req_id += 1

        pin_by_num = {
            p["pinNumber"]: p
            for p in pins
            if p["pinNumber"].isdigit() and int(p["pinNumber"]) <= SIGNAL_PIN_MAX
        }

        stub_top_len = max_stub_for_rotation(
            pin_nets,
            pin_by_num,
            TOP_ROTATION,
            char_pitch,
            margin,
            stub_top,
            long_stub,
            stub_scale,
            wire_gnd=wire_gnd,
            wire_nc=wire_nc,
        )
        stub_bottom_len = max_stub_for_rotation(
            pin_nets,
            pin_by_num,
            BOTTOM_ROTATION,
            char_pitch,
            margin,
            stub_bottom,
            long_stub,
            stub_scale,
            wire_gnd=wire_gnd,
            wire_nc=wire_nc,
        )
        mode = "uniform stub" if long_stub else f"safe-stub={SAFE_STUB}"
        print(
            f"{designator}: max stub top={stub_top_len} bottom={stub_bottom_len} mil "
            f"[{mode} scale={stub_scale}]"
        )

        if replace and not purge_all_wires:
            req_id, deleted = delete_wires_near_component(
                pins, req_id, dry_run, stub_top_len, stub_bottom_len
            )
            print(f"{designator}: deleted {deleted} old wires in bbox")

        wires_cache = api_invoke("eda.sch_PrimitiveWire.getAll", [], req_id)
        req_id += 1
        if not isinstance(wires_cache, list):
            wires_cache = []

        ok, skip, fail, replaced, kept = 0, 0, 0, 0, 0

        for pin_num in sorted(pin_by_num, key=int):
            net = pin_nets.get(pin_num)
            if not net:
                skip += 1
                continue
            if net == "NC" and not wire_nc:
                skip += 1
                continue
            if net == "GND" and not wire_gnd:
                skip += 1
                continue

            pin = pin_by_num[pin_num]
            rot = pin.get("rotation", TOP_ROTATION)
            if rot == TOP_ROTATION:
                stub = stub_top_len
            elif rot == BOTTOM_ROTATION:
                stub = stub_bottom_len
            else:
                stub = max(stub_top_len, stub_bottom_len)

            px, py = pin["x"], pin["y"]
            line = wire_line_pin_direction(px, py, rot, stub, flip)

            if dry_run:
                if pin_num in ("1", "2", "79", "80"):
                    print(
                        f"  {designator}.{pin_num} -> {net}  label@({px},{py})  "
                        f"wire {line} stub={stub}"
                    )
                ok += 1
                continue

            existing = wire_at_pin(wires_cache, pin)
            if existing:
                old_len = wire_length(normalize_line(existing.get("line") or []))
                if abs(old_len - stub) <= COORD_TOL and existing.get("net") == net:
                    kept += 1
                    ok += 1
                    continue
                api_invoke("eda.sch_PrimitiveWire.delete", [[existing["primitiveId"]]], req_id)
                req_id += 1
                wires_cache = [
                    w for w in wires_cache if w["primitiveId"] != existing["primitiveId"]
                ]
                replaced += 1

            try:
                created = api_invoke("eda.sch_PrimitiveWire.create", [line, net], req_id)
                req_id += 1
                wires_cache.append(created)
                ok += 1
            except Exception as exc:  # noqa: BLE001
                print(f"FAIL {designator}.{pin_num} ({net}): {exc}", file=sys.stderr)
                fail += 1

        print(
            f"{designator}: assigned {ok}, kept {kept}, replaced {replaced}, "
            f"skipped {skip}, failed {fail}"
        )

    if not dry_run:
        saved = api_invoke("eda.sch_Document.save", [], req_id)
        print(f"save: {saved}")


def main() -> None:
    parser = argparse.ArgumentParser(description="Assign DF17 carrier nets via JLCEDA MCP")
    parser.add_argument("--dry-run", action="store_true")
    parser.add_argument("--replace", action="store_true")
    parser.add_argument("--purge-all-wires", action="store_true", help="Delete every wire on page before assign")
    parser.add_argument("--designator", help="Only U1 or U2")
    parser.add_argument("--char-pitch", type=int, default=CHAR_PITCH)
    parser.add_argument("--margin", type=int, default=MARGIN)
    parser.add_argument("--stub-top", type=int, default=None)
    parser.add_argument("--stub-bottom", type=int, default=None)
    parser.add_argument("--stub-scale", type=float, default=STUB_SCALE, help="Stub length multiplier (default 1/3)")
    parser.add_argument("--flip", action="store_true", help="Reverse fanout direction")
    parser.add_argument(
        "--safe-stub",
        action="store_true",
        help="Use 8 mil stub only (default: uniform stub from longest net name)",
    )
    parser.add_argument(
        "--skip-gnd",
        action="store_true",
        help="Skip GND pins (default: wire and label GND)",
    )
    parser.add_argument(
        "--wire-nc",
        action="store_true",
        help="Wire NC pins with net name NC (default: skip; use assign_nc_no_connect.py)",
    )
    args = parser.parse_args()

    try:
        assign_nets(
            dry_run=args.dry_run,
            only=args.designator,
            replace=args.replace,
            char_pitch=args.char_pitch,
            margin=args.margin,
            stub_top=args.stub_top,
            stub_bottom=args.stub_bottom,
            flip=args.flip,
            long_stub=not args.safe_stub,
            purge_all_wires=args.purge_all_wires,
            stub_scale=args.stub_scale,
            wire_gnd=not args.skip_gnd,
            wire_nc=args.wire_nc,
        )
    except urllib.error.URLError as exc:
        print("无法连接 JLCEDA MCP (http://127.0.0.1:7655)。", file=sys.stderr)
        raise SystemExit(1) from exc


if __name__ == "__main__":
    main()

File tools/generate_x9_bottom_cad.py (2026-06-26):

#!/usr/bin/env python3
"""根据 X9 Core 底面机械图生成 DXF（原点 = 几何中心）。"""

from __future__ import annotations

import math
from pathlib import Path

import ezdxf
from ezdxf.enums import TextEntityAlignment
from ezdxf.math import Vec2

ROOT = Path(__file__).resolve().parents[1]
OUT_DIR = ROOT / "docs" / "DF17" / "cad"
OUT_DXF = OUT_DIR / "X9-Core-bottom.dxf"

# --- 图纸标注尺寸 (mm) ---
BOARD_HALF = 19.40
MOUNT_XY = 16.0
MOUNT_DIA = 2.10
MOUNT_CB_DIA = 3.60
MOUNT_CB_DEPTH = 0.65

CONN_CENTER_X = 16.0
CONN_LEN_Y = 24.0  # 图纸标注
CONN_HALF_Y = CONN_LEN_Y / 2
CONN_WIDTH_X = 4.0  # 图纸示意宽度（壳体投影）

CENTER_RIB_HALF_W = 7.0  # 14 / 2
CENTER_RIB_H = 20.0

M2_DIA = 1.60
M2_POS = [
    (0.0, 0.0),
    (-8.0, 6.0),   # 图纸未标 Y，按底视图比例估算，导入后请核对
    (-8.0, -6.0),
]

# Hirose DF17-80 触点区（载板 footprint 参考，0.5mm pitch）
DF17_CONTACT_SPAN = 19.5
DF17_ROW_PITCH = 3.0
DF17_PITCH = 0.5
DF17_PINS_PER_ROW = 40


def rounded_rect_points(half_w: float, half_h: float, radius: float) -> list[Vec2]:
    r = min(radius, half_w, half_h)
    pts: list[Vec2] = []
    corners = [
        (half_w - r, half_h - r, 0),
        (-half_w + r, half_h - r, 90),
        (-half_w + r, -half_h + r, 180),
        (half_w - r, -half_h + r, 270),
    ]
    for cx, cy, start_deg in corners:
        for i in range(9):
            ang = math.radians(start_deg + i * (90 / 8))
            pts.append(Vec2(cx + r * math.cos(ang), cy + r * math.sin(ang)))
    return pts


def add_poly(msp, layer: str, points: list[Vec2], close: bool = True) -> None:
    msp.add_lwpolyline(
        [(p.x, p.y) for p in points],
        close=close,
        dxfattribs={"layer": layer},
    )


def add_center_ribs(msp) -> None:
    slot_w = 1.0
    gap = 1.4
    x0 = -((5 * slot_w + 4 * gap) / 2) + slot_w / 2
    for i in range(5):
        x = x0 + i * (slot_w + gap)
        msp.add_lwpolyline(
            [
                (x - slot_w / 2, -CENTER_RIB_H / 2),
                (x + slot_w / 2, -CENTER_RIB_H / 2),
                (x + slot_w / 2, CENTER_RIB_H / 2),
                (x - slot_w / 2, CENTER_RIB_H / 2),
            ],
            close=True,
            dxfattribs={"layer": "CENTER_RIBS"},
        )


def connector_box(cx: float) -> tuple[float, float, float, float]:
    return (
        cx - CONN_WIDTH_X / 2,
        -CONN_HALF_Y,
        cx + CONN_WIDTH_X / 2,
        CONN_HALF_Y,
    )


def add_df17_pads(msp, cx: float, part: str) -> None:
    """在连接器区域绘制 80pin 0.5mm 焊盘参考（双列）。"""
    span = (DF17_PINS_PER_ROW - 1) * DF17_PITCH
    y_top = span / 2
    rows_x = [cx - DF17_ROW_PITCH / 2, cx + DF17_ROW_PITCH / 2]
    pad_r = 0.15
    for row_idx, px in enumerate(rows_x):
        for i in range(DF17_PINS_PER_ROW):
            py = y_top - i * DF17_PITCH
            msp.add_circle(
                (px, py),
                pad_r,
                dxfattribs={"layer": "DF17_PADS"},
            )
    x1, y1, x2, y2 = connector_box(cx)
    msp.add_text(
        part,
        height=0.8,
        dxfattribs={"layer": "TEXT"},
    ).set_placement((cx, y2 + 1.2), align=TextEntityAlignment.CENTER)


def add_pin1_marker(msp, cx: float) -> None:
    x1, y1, _, y2 = connector_box(cx)
    msp.add_circle((x1 + 0.6, y2 - 0.6), 0.35, dxfattribs={"layer": "PIN1_MARK"})
    msp.add_text(
        "1",
        height=0.6,
        dxfattribs={"layer": "PIN1_MARK"},
    ).set_placement((x1 + 0.6, y2 - 0.6), align=TextEntityAlignment.MIDDLE_CENTER)


def add_dimensions(msp) -> None:
    def dim_h(y: float, x1: float, x2: float, label: str) -> None:
        msp.add_linear_dim(
            base=(0, y - 2.5),
            p1=(x1, y),
            p2=(x2, y),
            dimstyle="EZDXF",
            override={"dimtxt": 1.8, "layer": "DIM"},
        ).render()
        msp.add_text(label, height=1.5, dxfattribs={"layer": "TEXT"}).set_placement(
            ((x1 + x2) / 2, y - 4.5), align=TextEntityAlignment.CENTER
        )

    def dim_v(x: float, y1: float, y2: float, label: str) -> None:
        msp.add_linear_dim(
            base=(x - 2.5, 0),
            p1=(x, y1),
            p2=(x, y2),
            angle=90,
            dimstyle="EZDXF",
            override={"dimtxt": 1.8, "layer": "DIM"},
        ).render()
        msp.add_text(label, height=1.5, dxfattribs={"layer": "TEXT"}).set_placement(
            (x - 4.5, (y1 + y2) / 2), align=TextEntityAlignment.MIDDLE_CENTER
        )

    dim_h(-BOARD_HALF - 1, -BOARD_HALF, BOARD_HALF, "38.80")
    dim_v(-BOARD_HALF - 6, -BOARD_HALF, BOARD_HALF, "38.80")
    dim_h(BOARD_HALF + 3, -MOUNT_XY, MOUNT_XY, "32.00")
    dim_v(-BOARD_HALF - 10, -CONN_HALF_Y, CONN_HALF_Y, "24.00")
    dim_h(-BOARD_HALF - 10, -CONN_CENTER_X, 0, "16.00")


def build() -> None:
    OUT_DIR.mkdir(parents=True, exist_ok=True)
    doc = ezdxf.new("R2010")
    doc.units = ezdxf.units.MM
    doc.header["$INSUNITS"] = 4
    msp = doc.modelspace()

    layers = {
        "OUTLINE": 7,
        "MOUNT_HOLES": 1,
        "MOUNT_CB": 3,
        "CONNECTOR": 4,
        "DF17_PADS": 8,
        "CENTER_RIBS": 9,
        "M2_HOLES": 6,
        "PIN1_MARK": 2,
        "TEXT": 7,
        "DIM": 5,
        "CENTERLINE": 140,
    }
    for name, color in layers.items():
        doc.layers.add(name, color=color)
        if name == "CENTERLINE":
            doc.layers.get(name).dxf.linetype = "CENTER"

    # 外轮廓（R3 圆角）
    outline = rounded_rect_points(BOARD_HALF, BOARD_HALF, 3.0)
    add_poly(msp, "OUTLINE", outline)

    # 安装孔
    for sx, sy in ((1, 1), (-1, 1), (-1, -1), (1, -1)):
        cx, cy = sx * MOUNT_XY, sy * MOUNT_XY
        msp.add_circle((cx, cy), MOUNT_CB_DIA / 2, dxfattribs={"layer": "MOUNT_CB"})
        msp.add_circle((cx, cy), MOUNT_DIA / 2, dxfattribs={"layer": "MOUNT_HOLES"})
        msp.add_text(
            f"φ{MOUNT_DIA}贯穿\nφ{MOUNT_CB_DIA}↓{MOUNT_CB_DEPTH}",
            height=0.7,
            dxfattribs={"layer": "TEXT"},
        ).set_placement((cx + 2.2, cy + 2.2))

    # 两颗 DF17 投影
    for cx, part in ((-CONN_CENTER_X, "DF17(3.0)-80DS"), (CONN_CENTER_X, "DF17(1.0H)-80DP")):
        x1, y1, x2, y2 = connector_box(cx)
        msp.add_lwpolyline(
            [(x1, y1), (x2, y1), (x2, y2), (x1, y2)],
            close=True,
            dxfattribs={"layer": "CONNECTOR"},
        )
        add_df17_pads(msp, cx, part)
        add_pin1_marker(msp, cx)

    add_center_ribs(msp)

    for x, y in M2_POS:
        msp.add_circle((x, y), M2_DIA / 2, dxfattribs={"layer": "M2_HOLES"})
    msp.add_text(
        "3×φ1.60 ↓3  /  M2-6H ↓3",
        height=0.7,
        dxfattribs={"layer": "TEXT"},
    ).set_placement((-8, -9.5))

    # 中心线
    msp.add_line((-BOARD_HALF - 5, 0), (BOARD_HALF + 5, 0), dxfattribs={"layer": "CENTERLINE"})
    msp.add_line((0, -BOARD_HALF - 5), (0, BOARD_HALF + 5), dxfattribs={"layer": "CENTERLINE"})
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

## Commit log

2026-06-25 Initial commit: X9 Core carrier board docs and tools.
    DF17 pinout docs, carrier PCB DXF generators, schematic spec, and JLCEDA MCP setup scripts.
    [X9-Core-bottom.dwg, X9-Core-bottom.dxf, carrier-pcb.dxf]
2026-06-26 Add carrier-side DF17 pinout docs and net assignment tooling.
    Separate Core vs carrier pin tables, extend the pinout DB schema, and add scripts to generate carrier markdown, remap pinouts, and assign schematic nets via JLCEDA MCP.
